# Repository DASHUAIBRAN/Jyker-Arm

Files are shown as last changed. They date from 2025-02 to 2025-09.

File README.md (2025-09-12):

# jyker机械臂

#### 硬件介绍
jyker 机械臂是一款开源的3D 打印机械臂，硬件分为4个部分
1.  3D打印的骨架 ，可以打开models 文件夹查看，也可以在makerworld上可以直接打印，传送门：https://makerworld.com.cn/zh/models/958314#profileId-973439
2.  3D打印的减速机4个以及金属减速机1个，也可以直接在makerworld上直接找到：https://makerworld.com.cn/zh/models/807709#profileId-785035
3.  FOC 板子可以上淘宝购买：https://item.taobao.com/item.htm?abbucket=17&id=975169994702 
或者去立创开源广场获取制板文件：https://oshwhub.com/dashuaibran/works ， 
FOC电机源码在firmware/CtrlStepDriver 目录下，
电机上位机源码在 MotorControl 目录下

#### 螺钉安装（打印减速器版本）
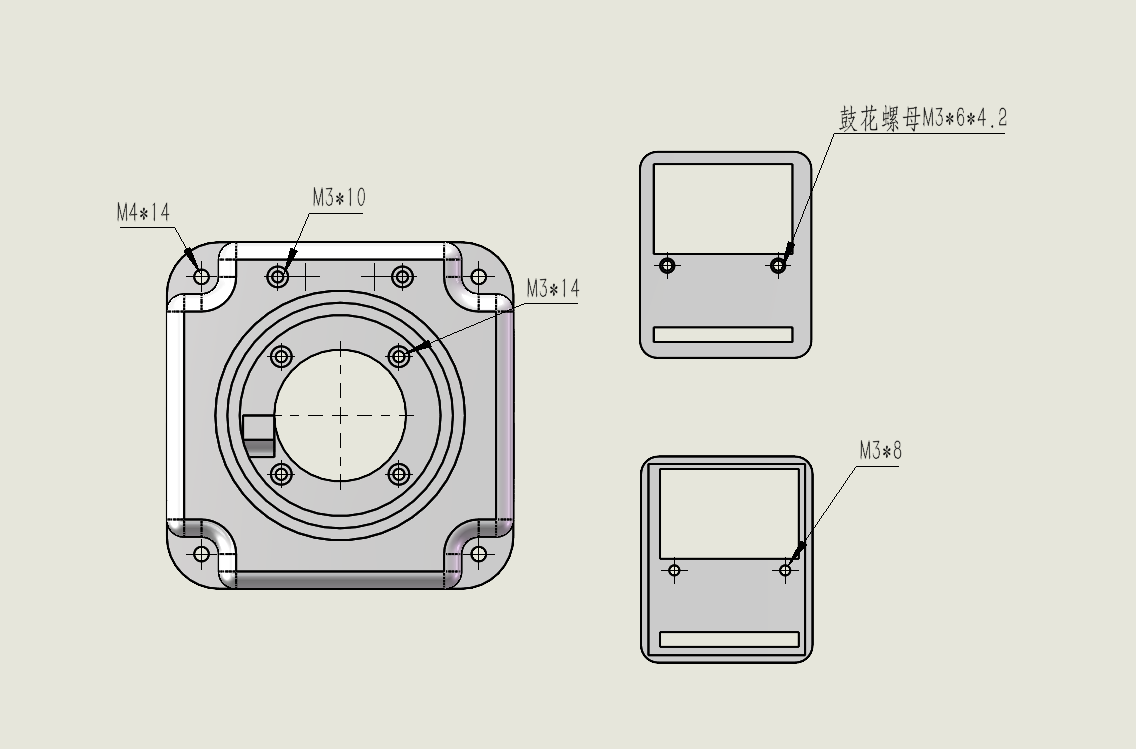
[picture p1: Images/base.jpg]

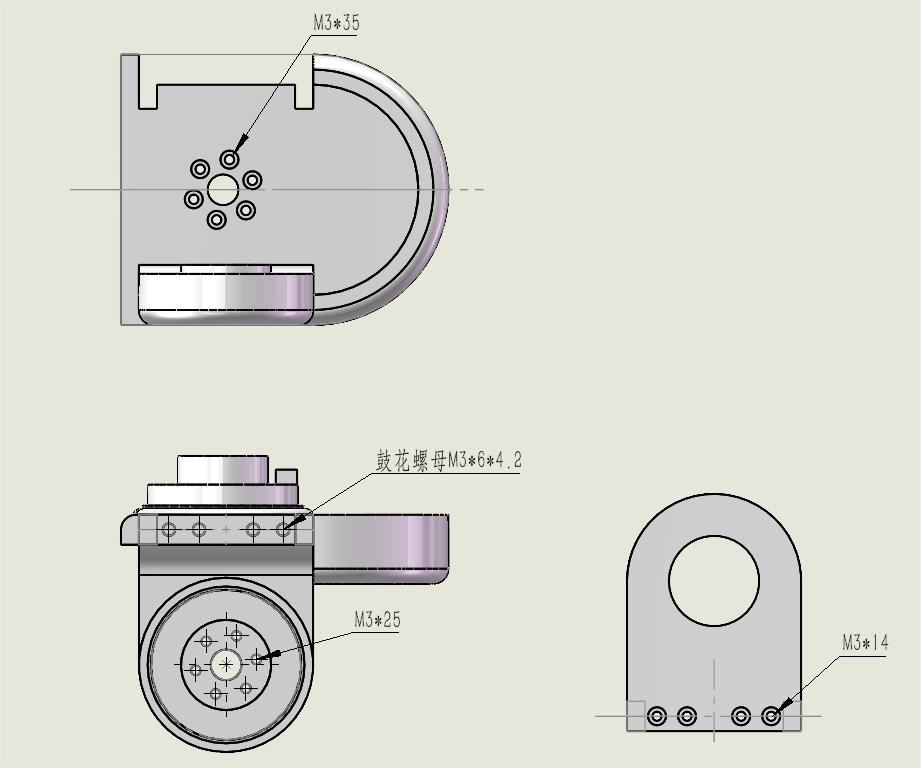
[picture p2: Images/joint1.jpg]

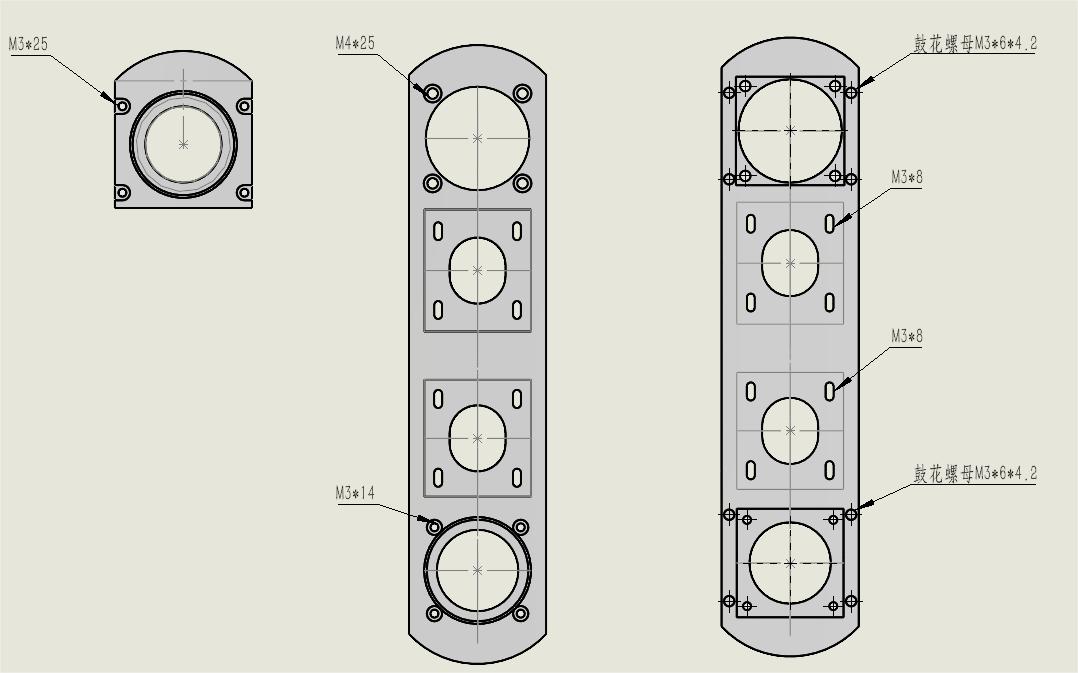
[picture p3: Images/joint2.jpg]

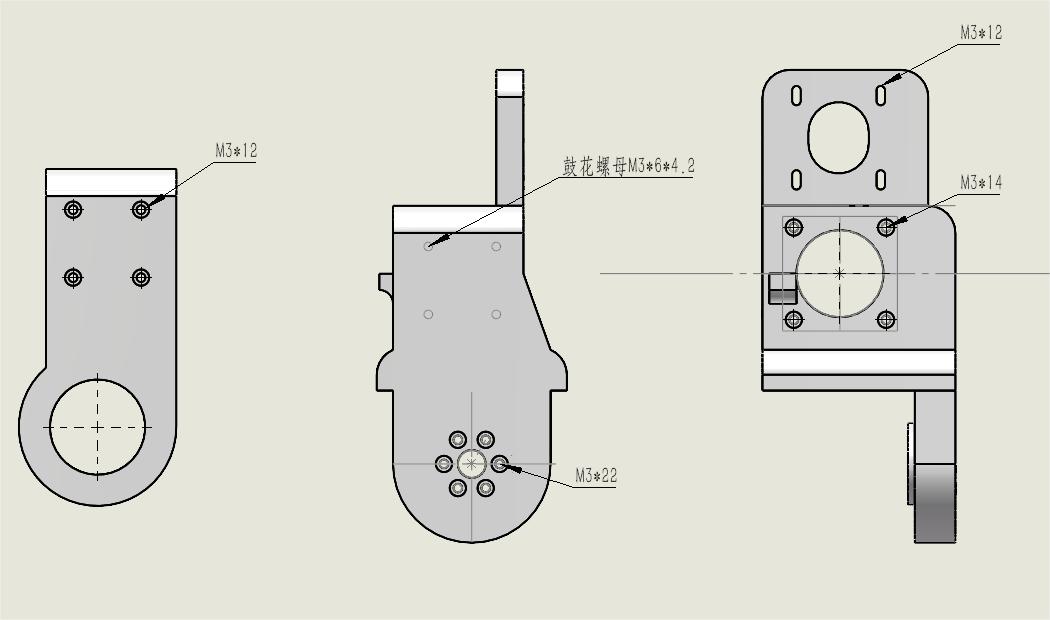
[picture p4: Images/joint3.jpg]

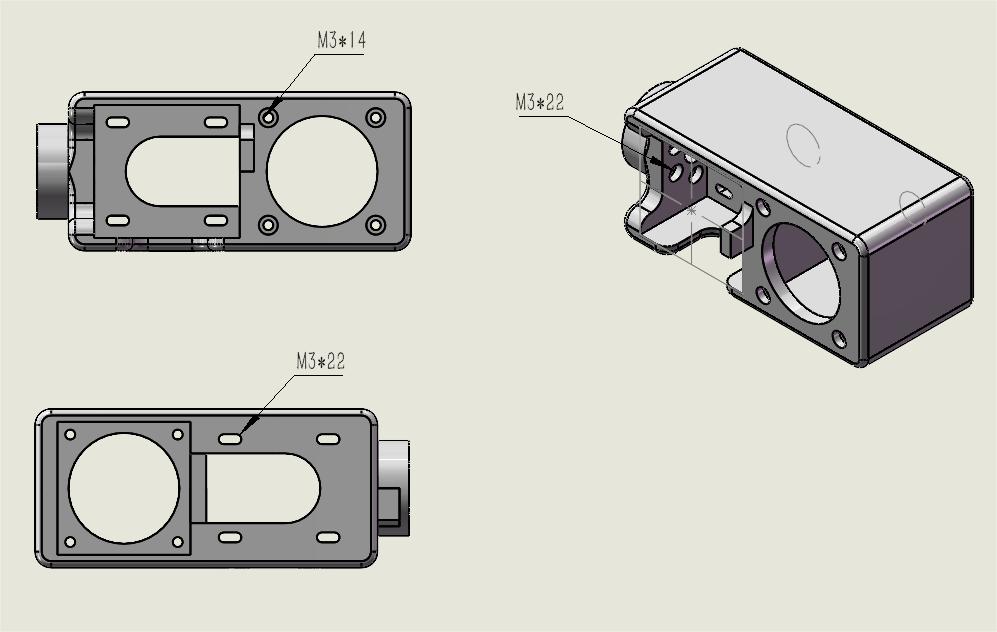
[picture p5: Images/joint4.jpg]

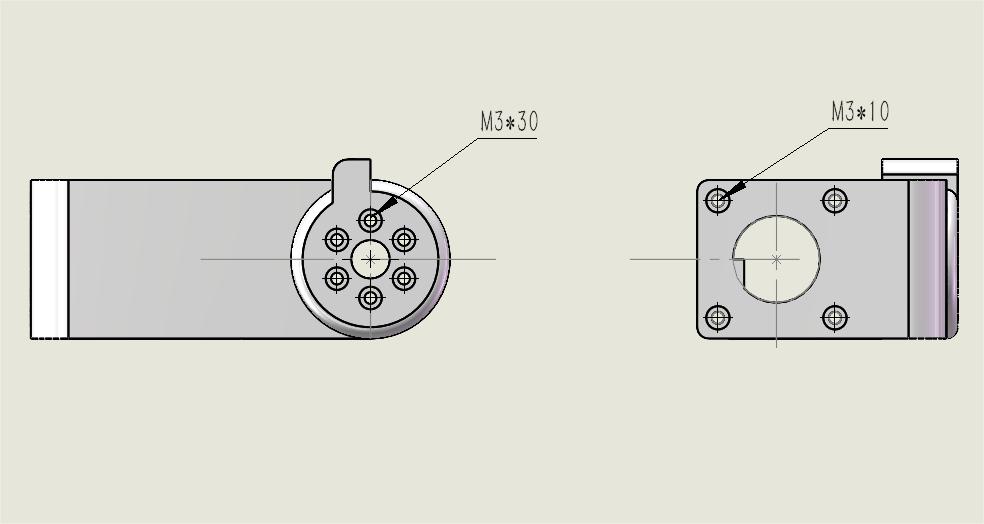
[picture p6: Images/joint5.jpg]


#### 螺钉安装（金属减速器版本）
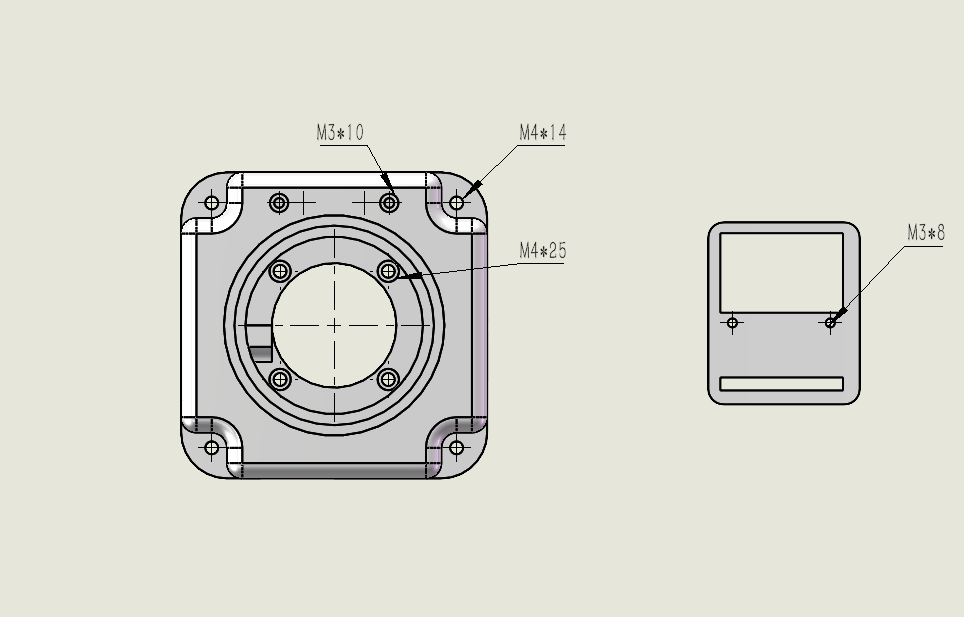
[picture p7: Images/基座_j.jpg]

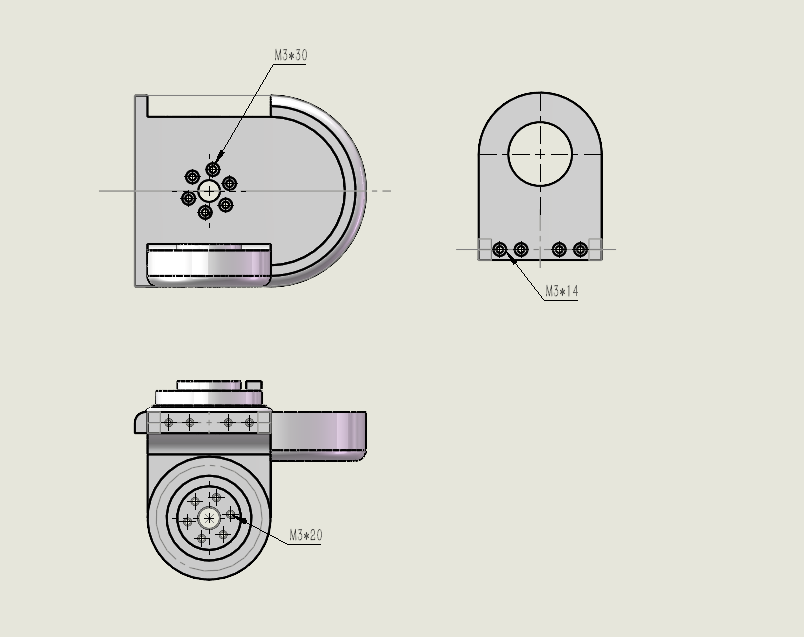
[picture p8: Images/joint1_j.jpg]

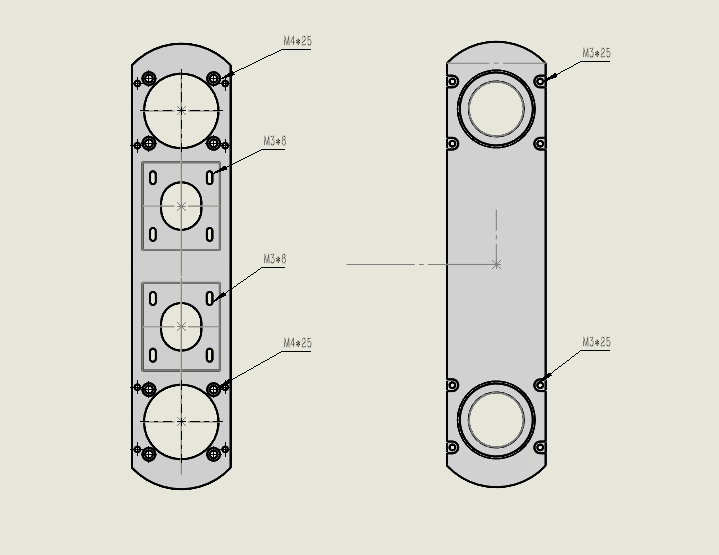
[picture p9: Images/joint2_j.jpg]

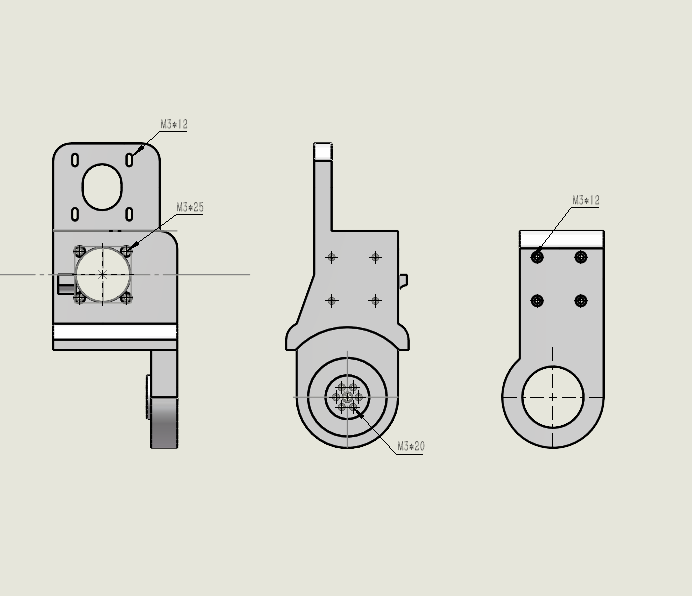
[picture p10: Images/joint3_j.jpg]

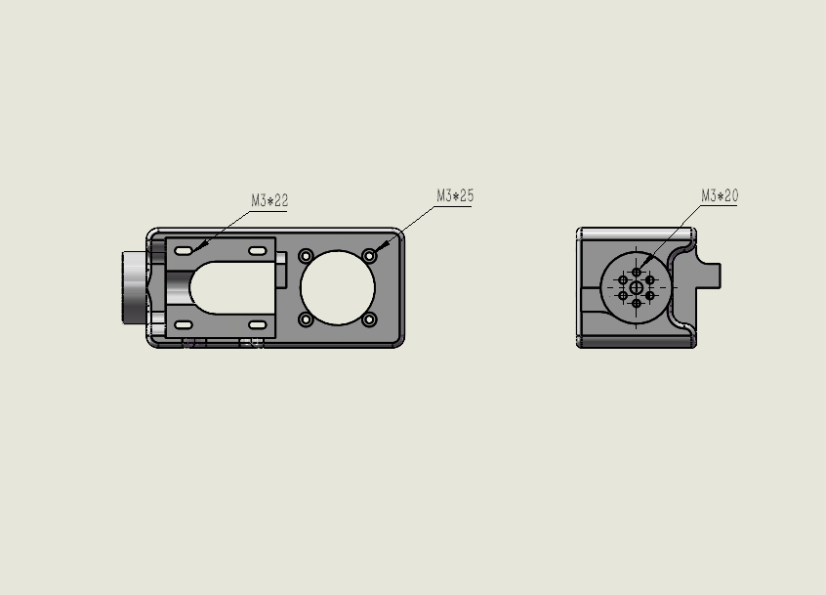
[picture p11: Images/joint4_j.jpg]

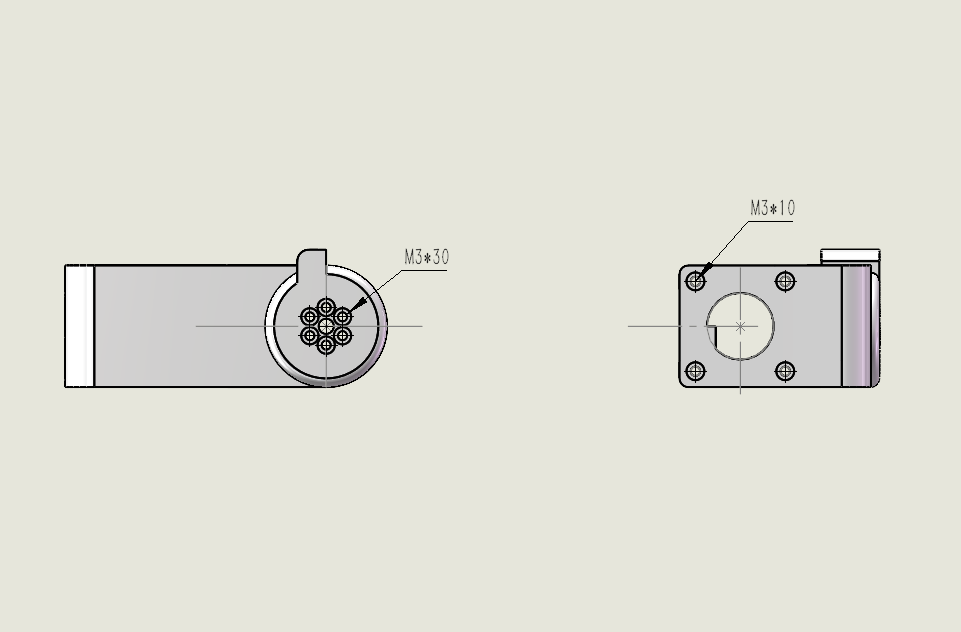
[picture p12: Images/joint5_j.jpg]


#### 电机对应位置以及ID设置
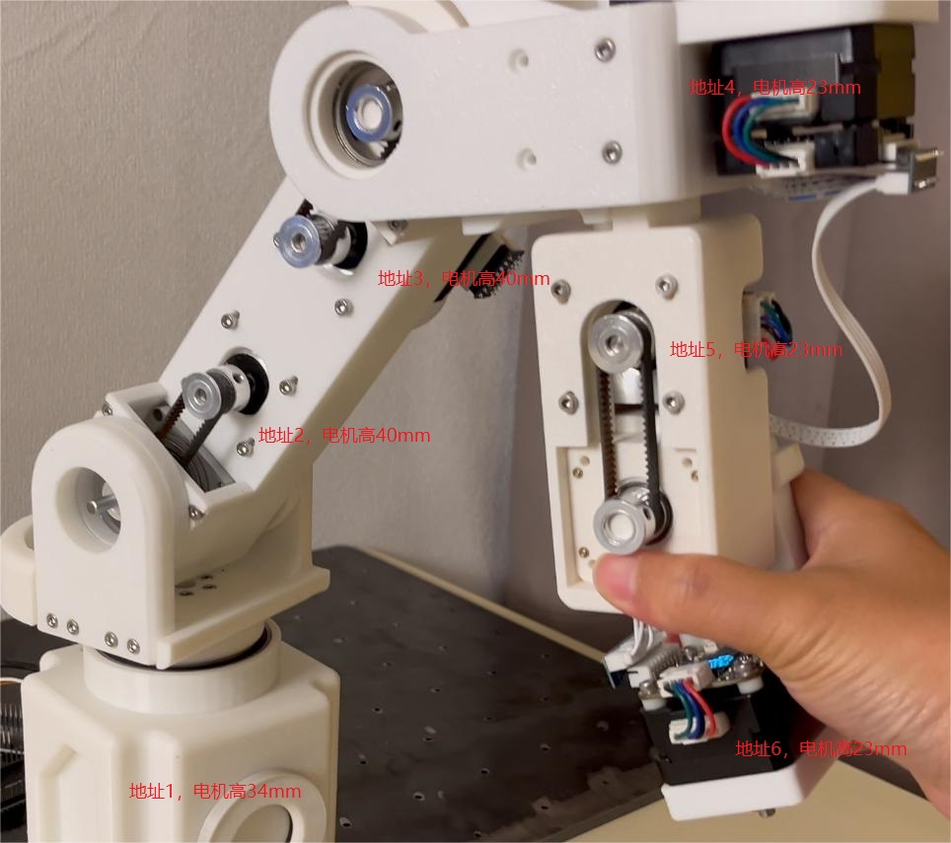
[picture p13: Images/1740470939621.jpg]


#### 夹爪
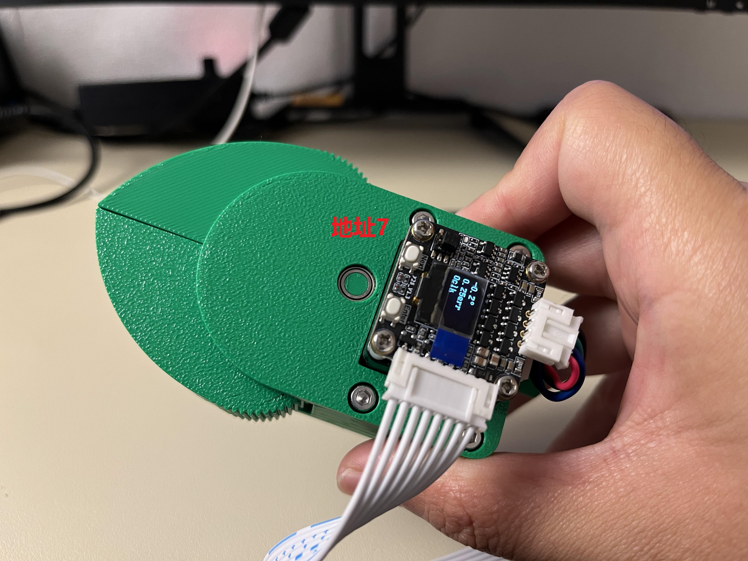
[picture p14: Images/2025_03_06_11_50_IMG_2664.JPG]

1.  模型在models/Claw 下面，也可以在makerworld上可以直接打印，传送门：https://makerworld.com.cn/zh/models/1006461-jyker-jia-zhua#profileId-1033256
2.  软件还是 HMIcode/BigProject目录下。

#### 安装教程
https://www.bilibili.com/video/BV1816yYHE2C/?vd_source=d81fb23162409ba3460eb9de840d7b4a

#### 软件使用

1. TODO

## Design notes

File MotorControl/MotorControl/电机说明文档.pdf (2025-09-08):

目录

## 一、电机说明

1.1.电机接口图

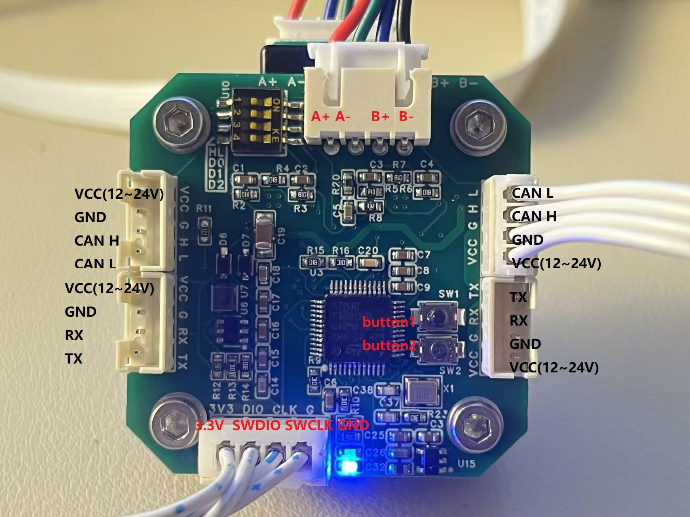
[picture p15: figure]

1.2.电机接口说明

1.2.1 电机支持串口通讯以及 can 通讯。
1.2.2 电机有两个串口通讯口，以及两个 can 通讯口，均可连接接线板，有两个通讯口是方 便后续串联电机。
1.2.3 串口通讯引脚有 VCC、GND、RX、TX，VCC 是电源输入，接受 12V 到 24V 之间的宽电 压，GND 接地，RX 接通讯的 TX 端 ，TX 接通讯的 RX 端。
1.2.4 CAN 通讯引脚有 VCC、GND、CAN H 、CAN L，VCC 是电源输入，接受 12V 到 24V 之 间的宽电压，GND 接地，CANH 接通讯的 CANH ,CANL 接通讯的 CANL。
1.2.5 支持 SWD 进行调试或编程，该接口可接 ST-LINK、J-LINK、DAP-LINK，四个引脚分别是 3V3、DIO、CLK、GND。
1.2.6 电机接口 A+ A- B+ B- 可接 42 步进电机。
1.2.7 有两个 button ,button1 长按可校准电机、button2 单击可使能电机或是失能电机。

### 1.3 电机接线示意图

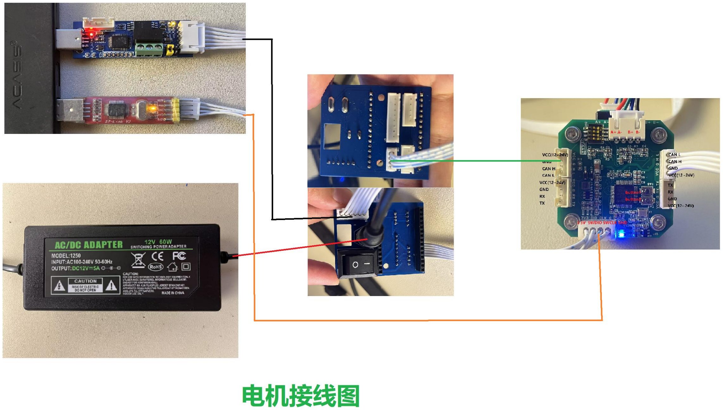
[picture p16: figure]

### 1.4 电机接线说明

1.4.1 红线是电源与中间集线板的连线，并没有什么讲究，直接插入就行。
1.4.2 橙色线是 ST-Link 与电机控制板之间的连线，请对准接口。
1.4.3 黑色线是 USB 转 CAN 模块与集线板的连接，如果购买 UP 的 USB 转 CAN 模块接口使 用 XH2.54 反向线连接便可以，如果购买其他品牌需要对应上接线定义。
1.4.4 绿色线是转接板与电机控制板的连线，可以使用 PH2.0 反向的线连接，如果使用面包 板或者其他接线方式，需要核对好接线定义。
1.4.5 以上所有可以在这个链接买到：
https://mall.bilibili.com/neul-next/detailuniversal/detail.html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 hare (https://mall.bilibili.com/neul-next/detailuniversal/detail.html?isMerchant=1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)

## 1.5 ID 设置

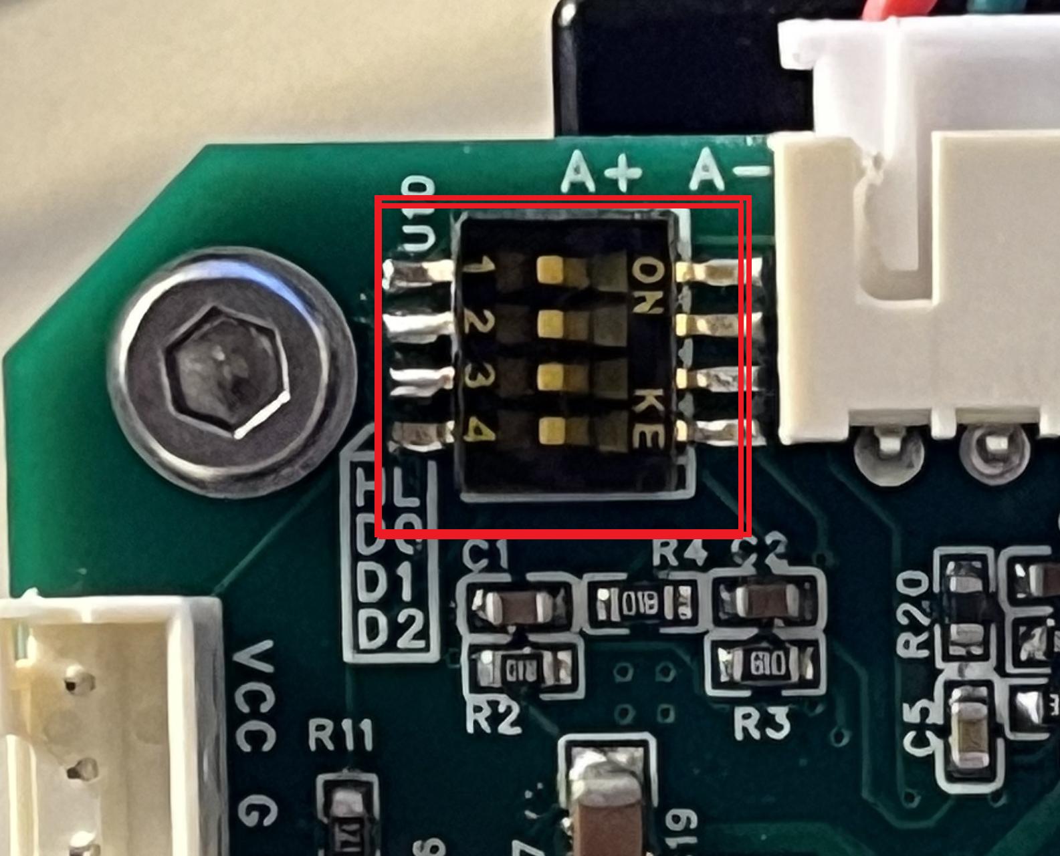
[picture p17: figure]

1.5.1 电机的 ID 有电机右上角的拨码器设置，由图可知有 1、2、3、4 四个拨码开关。

1.5.2 拨码开关 1 是通知 CANH 和 CANL 是通过 120R 电阻接通，在多点电机串联的情况下， 中间电机拨码开关关闭，最后一个电机拨码开关需要关闭。

1.5.3 拨码开关 2、3、4 用于控制电机 ID，分别代表 4、2、1，举例说明，像上图拨码开关
2、3、4 都关闭，电机 ID 为 4*0+2*0+1*0 =0 ；
如果 4、3 关闭，2 打开，电机 ID 为：4×0 + 2×0 + 1×1 = 1
如果 4、2 关闭，3 打开，电机 ID 为：4×0 + 2×1 + 1×0 = 2
如果 4 关闭，3、2 打开，电机 ID 为：4×0 + 2×1 + 1×1 = 3 如果 3、2 关闭，4 打开，电机 ID 为：4×1 + 2×0 + 1×0 = 4
如果 3 关闭，4、2 打开，电机 ID 为：4×1 + 2×0 + 1×1 = 5
如果 2 关闭，4、3 打开，电机 ID 为：4×1 + 2×1 + 1×0 = 6
如果 4、3、2 拨码开关都打开，电机 ID 为：4×1 + 2×1 + 1×1 = 7

## 二、通讯协议说明

### 2.1 使用 ID 读取信息

## 2.1.1 节点地址与帧 ID

节点 ID (Node ID): 驱动器通过拨码开关或配置命令设置其唯一的节点 ID，范围为 0x00 到
0x07。
命令帧 ID (Command ID): 上位机发送命令的 ID 格式为 0x0XX，其中 XX 为命令码。
响应帧 ID (Response ID): 驱动器发送响应的 ID 格式为 (NodeID << 7) | 0x2X。
例如，节点 ID 为 3 的驱动器，其响应 ID 的计算为 (3 << 7) | 0x21 = 0x180 | 0x21 = 0x1A1。
数据格式： 所有浮点数和 32 位整数均按小端字节序（Little-Endian）传输。

## 2.1.2 命令集

2.1.2.1 控制命令 (0x00 ~ 0x0F)

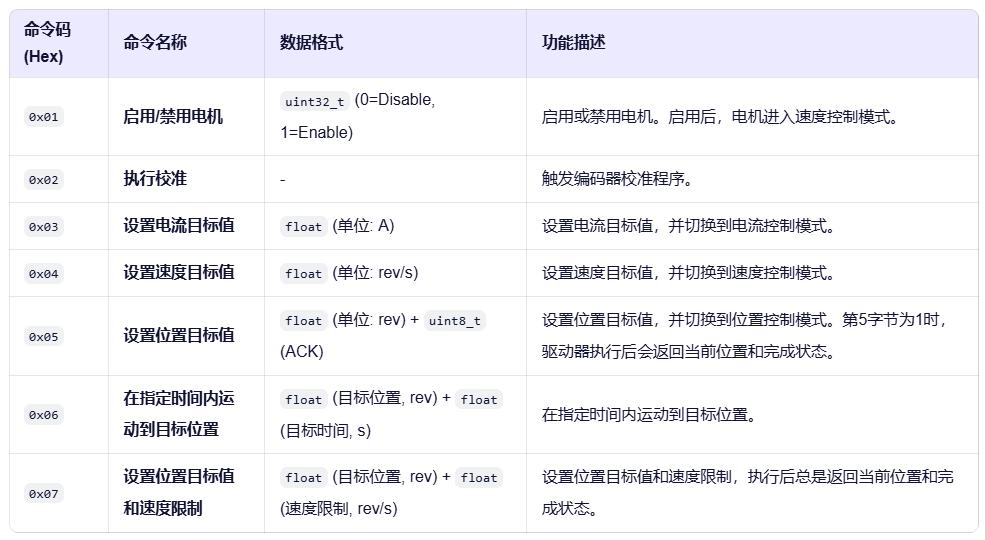
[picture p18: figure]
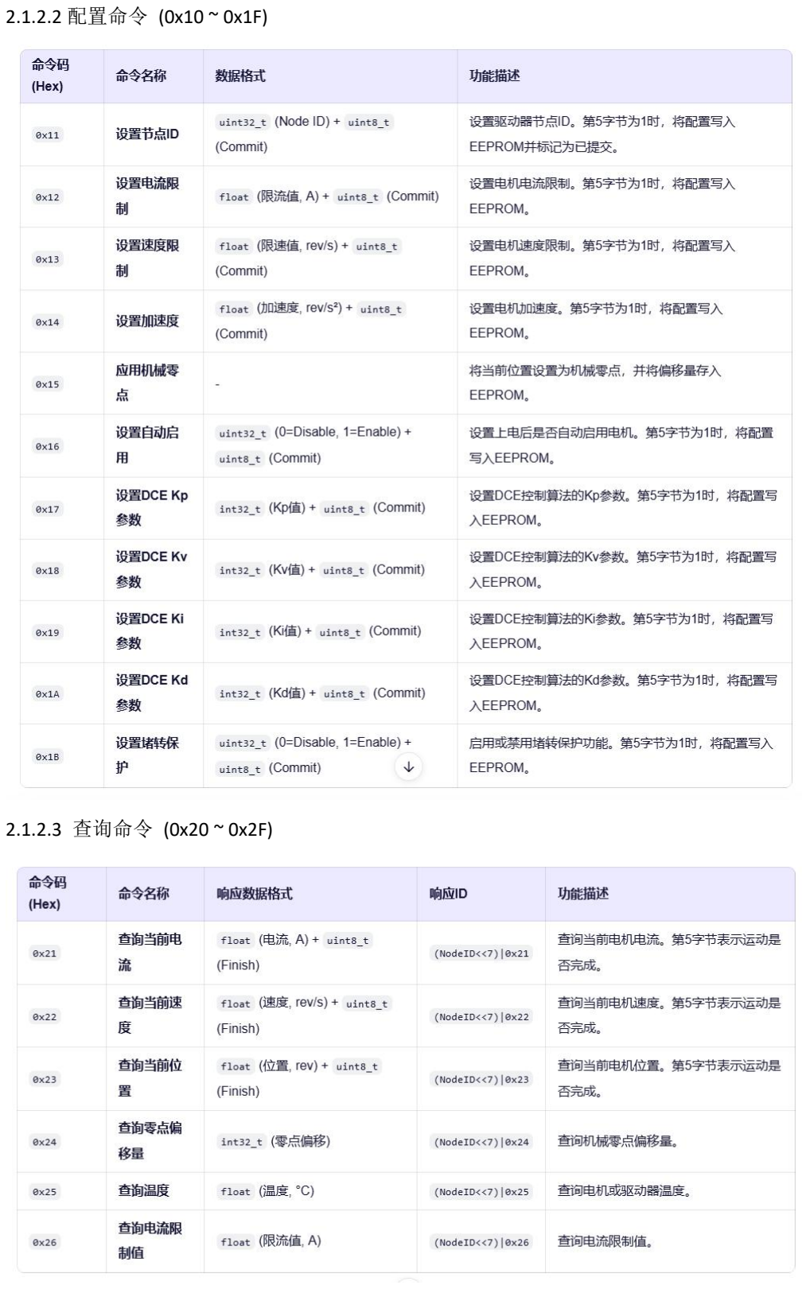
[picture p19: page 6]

2.1.2.2 配置命令 (0x10 ~ 0x1F)

2.1.2.3 查询命令 (0x20 ~ 0x2F)

## 三、上位机说明

### 3.1 上位机长这个样

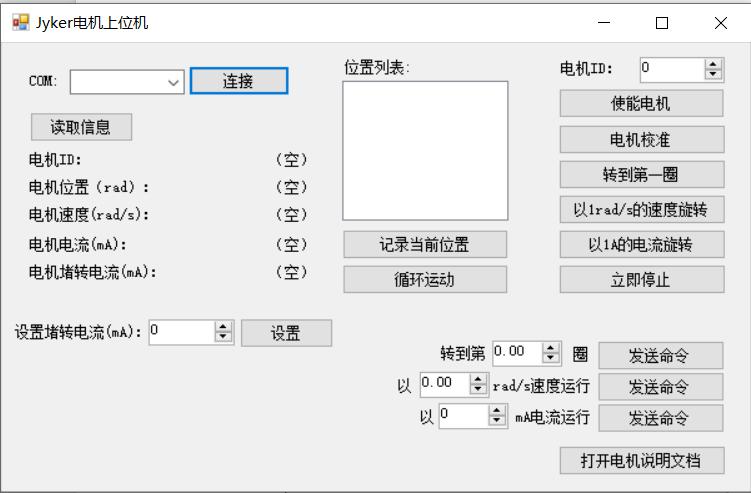
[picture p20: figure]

### 3.2 上位机使用说明

## 3.2.1 连接设备

使用 USB 线将电机驱动器连接到电脑。
打开上位机软件。
选择串口：点击“COM端口”下拉框，软件会自动列出所有可用的USB串口（如 COM3, COM4）。 建立连接：从列表中选择正确的串口号，然后点击 “连接” 按钮。 连接成功后，按钮文字会变为 “断开连接”，且串口号选择框将被锁定。 若连接失败，请检查 USB 线连接、驱动是否安装正确，并尝试重新选择串口。

### 3.2.2 读取电机状态

在 “电机 ID” 的数值框中输入目标电机的 ID 号。

点击 “读取信息” 按钮。
软件将自动查询并显示该电机的以下信息：
电流 (A)
速度 (rev/s)
位置 (rev)
限流值 (A)

### 3.2.3 基本电机控制

使能/失能电机：
点击 “使能电机” 按钮，电机将通电并准备运行（按钮变为“失能电机”）。 点击 “失能电机” 按钮，电机将断电（按钮变回“使能电机”）。 执行校准：
点击 “校准电机” 按钮，驱动器将执行编码器校准程序。
快速测试（以 1 单位运行）：
转一圈：点击此按钮，电机将旋转一整圈。
一圈每秒：点击此按钮，电机将以每秒一圈的速度旋转。
1A 电流：点击此按钮，电机将以 1A 的电流运行。 立即停止：
点击 “马上停止” 按钮，电机将立即停止运动。

### 3.2.4 参数设置与目标控制

设置目标值：
在对应的数值框中输入目标值。
点击右侧的 “设置” 按钮。
设置位置：输入目标圈数，点击“设置”让电机运动到该位置。 设置速度：输入目标速度（圈/秒），点击“设置”让电机以该速度运行。 设置电流：输入目标电流（A），点击“设置”让电机以该电流运行。 设置限流：输入电流限制值（A），点击“设置”来保护电机。

### 3.2.5 位置循环运动

记录位置点：
手动移动电机到一个目标位置。
点击 “记录当前位置” 按钮，该位置（圈数）将被添加到下方的列表中。 重复此过程，记录所有需要循环运动的位置点。
启动循环运动：
点击 “循环运动” 按钮。
软件将按列表中的顺序，依次发送指令让电机运动到每一个记录的位置点。 电机到达一个点后，会自动开始向下一个点运动。
停止循环：

点击 “马上停止” 按钮可以立即中断循环运动。

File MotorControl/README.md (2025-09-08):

电机控制上位机系统
基于 CAN 通信协议的智能电机控制上位机软件

本项目是一个用于控制支持 CAN 通信的智能电机驱动器的上位机软件，支持电机状态读取、基本控制、参数设置和循环运动功能。

📋 功能特性
✅ 通过串口（SLCAN协议）与电机通信
✅ 支持多电机 ID 识别与控制
✅ 实时读取电流、速度、位置、限流值
✅ 电机使能/失能、校准、快速测试
✅ 目标位置、速度、电流设置
✅ 位置循环运动（支持记录与自动循环）
✅ 图形化界面，操作简单直观
🛠️ 硬件连接
使用 USB 线将电机驱动器连接至电脑。
驱动器支持 CAN 或串口通信，确保接线正确。
每台电机通过 拨码开关 设置唯一 ID（0-7）：
拨码开关 2、3、4 分别代表权重 1、2、4
例如：开关2打开，3、4关闭 → ID = 1
💻 软件使用说明
1. 连接设备
打开上位机软件。
从 “COM端口” 下拉框中选择正确的串口号（如 COM3）。
点击 “连接” 按钮建立连接。
✅ 连接成功后，按钮变为“断开连接”，串口选择框将被锁定。

2. 读取电机状态
在 “电机ID” 输入框中输入目标电机 ID。
点击 “读取信息” 按钮。
软件将显示：
电流 (A)
速度 (rev/s)
位置 (rev)
限流值 (A)
3. 基本控制
操作	说明
使能电机	通电，准备运行（点击后变为“失能电机”）
校准电机	执行编码器校准程序
转一圈	控制电机旋转一整圈
一圈每秒	控制电机以 1 rev/s 的速度运行
1A电流	控制电机以 1A 电流运行
马上停止	立即停止电机运动
4. 参数设置
在对应输入框中输入目标值，点击右侧 “设置” 按钮：

设置位置：运动到指定圈数
设置速度：以指定速度运行（rev/s）
设置电流：以指定电流运行（A）
设置限流：设置电流保护上限（A）
5. 位置循环运动
记录位置点：
手动移动电机到目标位置。
点击 “记录当前位置”，位置将添加到列表。
重复操作，记录多个点。
启动循环：
点击 “循环运动”，电机将按顺序循环运动到每个记录点。
停止循环：
点击 “马上停止” 可随时中断。
📄 通信协议（CAN）
命令码	功能	数据格式
0x01	使能/禁能	uint32_t
0x02	校准	-
0x03	设置电流	float (A)
0x04	设置速度	float (rev/s)
0x05	设置位置	float (rev) + ACK
0x21~0x26	查询状态	返回 float + 状态
详细协议请参考 CAN通信协议文档

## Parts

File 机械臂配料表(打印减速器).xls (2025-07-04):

材料 | 数量 | 备注 | 价格 | tb链接
42步进电机 40mm 长 | 2 |  | 454.65 | https://shop113302005.taobao.com/
42步进电机 23mm 长 | 3
42步进电机 34mm 长 | 1
42电机 foc 控制板 | 6
12V 电源适配器 | 1 | 12V5A | 35 | https://detail.tmall.com/item.htm?from=cart&id=645461549857&skuId=5151504175110
同步轮 2GT（20齿高16)内孔8mm | 3 |  | 10.79 | https://item.taobao.com/item.htm?_u=gvv76ou9fdf&id=528687341718&skuId=4086878159095
同步轮 2GT（20齿高16)内孔5mm | 5 |  | 10.79 | https://item.taobao.com/item.htm?_u=gvv76ou9fdf&id=528687341718&skuId=4086878159093
同步带 2GT-140MM（防滑齿面） | 4 |  | 14.18 | https://item.taobao.com/item.htm?_u=gvv76ou7974&id=677341747083&skuId=4863997853174
3d 打印谐波减速器第四版不出轴 | 1 | 在我另外一个开源链接里 | 53.06
3d 打印谐波减速器第四版出轴 | 3 | 在我另外一个开源链接里
金属谐波减速机 | 1 | MINIF 11-50（法兰输出） 可配42步进 | 260 | https://item.taobao.com/item.htm?_u=pvv76ou91cf&id=702811518003
定位销 | 1 | 5mm* 50mm | 5 | https://item.taobao.com/item.htm?_u=4vv76ou892c&id=754846150226&skuId=5376758051412
轴承 内径50mm外径65厚度7mm | 1 |  | 14.5 | https://item.taobao.com/item.htm?_u=gvv76oudd5c&id=732883595520&skuId=5298946319109
轴承 内径40mm外径52mm厚度7mm | 3 |  |  | https://item.taobao.com/item.htm?_u=gvv76oudd5c&id=732883595520&skuId=5146788376594
XH2.54mm 蓝白红白排线 8p 400mm | 2 | 建议去up工房买，单买算起来有点亏：https://mall.bilibili.com/neul-next/detailuniversal/detail.html?isMerchant=1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 | 10 | https://item.taobao.com/item.htm?_u=pvv76ou2ebb&id=520551443113&sku_properties=-2%3A-7
PH2.0mm蓝白红白排线 4p 400mm | 1
PH2.0mm蓝白红白排线 4p 200mm | 3
PH2.0mm蓝白红白排线 4p 100mm | 1
XH2.54mm 插座 4p | 1 |  | 16 | https://detail.tmall.com/item.htm?_u=pvv76oud8b8&id=609069698010&skuId=4450119279579
XH2.54mm 插座 5p | 1
XH2.54mm 插座 6p | 1
XH2.54mm 插座 8p | 1
PH2.00mm 插座 4p | 10
PH2.00mm 插座 8p | 1
2.54mm单排母座 8p | 5 |  | 10 | https://item.taobao.com/item.htm?_u=pvv76ou243a&id=543256078293&skuId=3268555613590
2.54mm单排母座 15p | 2
接线板子大 | 1 |  | 60 | https://oshwhub.com/dashuaibran/mechanical-arm-line-connector
接线板子小1 | 4
接线板子小2 | 1
3d 打印件 |  |  | 200
内六角螺丝圆柱螺钉M4*14 | 8 | 底座和底板之间的固定 | 60 | https://detail.tmall.com/item.htm?from=cart&id=664122354131&skuId=4959959431045
内六角螺丝圆柱螺钉M3*40 | 10 | 基座与第一轴的连接、基座电机和减速器连接
内六角螺丝圆柱螺钉M3*16 | 4 | 固定减速器和基座
注塑铜螺母滚花螺母 M3*6*4.2 | 8
内六角螺丝圆柱螺钉M3*12 | 50 | 2,3,4,5关节减速器固定
内六角螺丝圆柱螺钉M3*8 | 50 | 2,3,4关机电机固定
内六角螺丝圆柱螺钉M3*10
内六角螺丝圆柱螺钉M3*12
内六角螺丝圆柱螺钉M3*14
内六角螺丝圆柱螺钉M3*22 | 4 | 5关节电机固定
内六角螺丝圆柱螺钉M3*30 | 6 | 第3轴和减速器连接
内六角螺丝圆柱螺钉M3*20 | 4 | 第4轴和减速器连接
内六角螺丝圆柱螺钉M3*35
内六角螺丝圆柱螺钉M3*25 | 6 | 第5轴和减速器连接
 |  |  | 1213.97

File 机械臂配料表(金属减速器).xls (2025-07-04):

材料 | 数量 | 备注 | 价格 | tb链接
42步进电机 40mm 长 | 2 |  | 454.65 | https://shop113302005.taobao.com/
42步进电机 23mm 长 | 3
42步进电机 34mm 长 | 1
42电机 foc 控制板 | 6
12V 电源适配器 | 1 | 12V5A | 35 | https://detail.tmall.com/item.htm?from=cart&id=645461549857&skuId=5151504175110
同步轮 2GT（20齿高16)内孔8mm | 3 |  | 10.79 | https://item.taobao.com/item.htm?_u=gvv76ou9fdf&id=528687341718&skuId=4086878159095
同步轮 2GT（20齿高16)内孔5mm | 5 |  | 10.79 | https://item.taobao.com/item.htm?_u=gvv76ou9fdf&id=528687341718&skuId=4086878159093
同步带 2GT-140MM（防滑齿面） | 4 |  | 14.18 | https://item.taobao.com/item.htm?_u=gvv76ou7974&id=677341747083&skuId=4863997853174
金属谐波减速机 42_50 | 1 | MINIF 11-50（法兰输出） 可配42步进 | 260 | https://item.taobao.com/item.htm?_u=pvv76ou91cf&id=702811518003
金属谐波减速机 42_30 | 2 | MINIF11-30（法兰输出） 可配42步进 | 520 | https://item.taobao.com/item.htm?_u=pvv76ou91cf&id=702811518003
金属谐波减速机 30_30 |  | MINIF-8-30（法兰输出） 可配35步进 | 600 | https://item.taobao.com/item.htm?_u=pvv76ou91cf&id=702811518003&skuId=4952528325501
定位销 | 4 | 5mm* 50mm | 5 | https://item.taobao.com/item.htm?_u=4vv76ou892c&id=754846150226&skuId=5376758051412
轴承 内径50mm外径65厚度7mm | 1 |  | 14.5 | https://item.taobao.com/item.htm?_u=gvv76oudd5c&id=732883595520&skuId=5298946319109
轴承 内径40mm外径52mm厚度7mm | 2 |  |  | https://item.taobao.com/item.htm?_u=gvv76oudd5c&id=732883595520&skuId=5146788376594
轴承 内径5mm外径10mm厚度4mm | 4 | 用于固定减速器的底部 | 10 | https://detail.tmall.com/item.htm?abbucket=17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
XH2.54mm 蓝白红白排线 8p 400mm | 2 | 建议去up工房买，单买算起来有点亏：https://mall.bilibili.com/neul-next/detailuniversal/detail.html?isMerchant=1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 | 10 | https://item.taobao.com/item.htm?_u=pvv76ou2ebb&id=520551443113&sku_properties=-2%3A-7
PH2.0mm蓝白红白排线 4p 400mm | 1
PH2.0mm蓝白红白排线 4p 200mm | 3
PH2.0mm蓝白红白排线 4p 100mm | 1
XH2.54mm 插座 4p | 1 |  | 16 | https://detail.tmall.com/item.htm?_u=pvv76oud8b8&id=609069698010&skuId=4450119279579
XH2.54mm 插座 5p | 1
XH2.54mm 插座 6p | 1
XH2.54mm 插座 8p | 1
PH2.00mm 插座 4p | 10
PH2.00mm 插座 8p | 1
2.54mm单排母座 8p | 5 |  | 10 | https://item.taobao.com/item.htm?_u=pvv76ou243a&id=543256078293&skuId=3268555613590
2.54mm单排母座 15p | 2
接线板子大 | 1 |  | 60 | https://oshwhub.com/dashuaibran/mechanical-arm-line-connector
接线板子小1 | 4
接线板子小2 | 1
3d 打印件 |  |  | 200
内六角螺丝圆柱螺钉M4*14 | 8 |  | 60 | https://detail.tmall.com/item.htm?from=cart&id=664122354131&skuId=4959959431045
内六角螺丝圆柱螺钉M4*30 | 12
内六角螺丝圆柱螺钉M3*12 | 8
内六角螺丝圆柱螺钉M3*8 | 10
内六角螺丝圆柱螺钉M3*10 | 2
内六角螺丝圆柱螺钉M3*14 | 4
内六角螺丝圆柱螺钉M3*22 | 4
内六角螺丝圆柱螺钉M3*30 | 6
内六角螺丝圆柱螺钉M3*20 | 18
内六角螺丝圆柱螺钉M3*25 | 16
 |  |  | 2290.91

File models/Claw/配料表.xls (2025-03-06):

材料 | 数量 | 备注 | 链接
3D 打印件 | 1 |  | https://makerworld.com.cn/zh/models/1006461-jyker-jia-zhua#profileId-1033256
28电机以及FOC控制板 | 1 | 电机使用28-28长磁柱电机就行 | https://item.taobao.com/item.htm?_u=6vv76ou3929&id=692429189361&skuId=5731955776564
轴承15*10*4 | 1 |  | https://item.taobao.com/item.htm?_u=6vv76ou8b88&id=642277669910&sku_properties=122276018%3A20213
轴承10*5*4 | 6 |  | https://item.taobao.com/item.htm?_u=6vv76ou7de7&id=674305780577&sku_properties=122276018%3A20213
螺钉 M3*35 | 4 |  | https://detail.tmall.com/item.htm?_u=6vv76ou5bd4&id=664122354131
滚花螺母 M3*6*4.2 | 4 |  | https://detail.tmall.com/item.htm?_u=6vv76ou55ed&id=580863677562

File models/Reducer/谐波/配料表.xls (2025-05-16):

物料 | 数量
轴承 6706-ZZ【30*37*4】 | 1
轴承 内径12外径18厚度4 | 1
轴承 内径10外径15厚度4 | 1
注塑铜螺母滚花螺母 M3*6*4.2 | 10
注塑铜螺母滚花螺母 M2*6*3.2 | 4
钢圆头内六角螺丝圆柱螺钉 M2*35 (https://item.taobao.com/item.htm?spm=a1z09.2.0.0.6c082e8d8Twp98&id=664122354131&_u=ovv76ou61e7) | 4
3D 打印件 |  | https://makerworld.com.cn/zh/models/807709-jyker-xie-bo-jian-su-qi#profileId-785035
304不锈钢球轴承滚珠不锈钢钢珠实心钢珠精密小钢珠钢球2.0毫米 (https://item.taobao.com/item.htm?spm=a1z09.2.0.0.6c082e8dgtaKx1&id=617921831316&_u=qvv76oud0d6) | 45~55颗
润滑油 | 1
500目砂纸 | 1

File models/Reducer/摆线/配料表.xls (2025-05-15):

物料 | 数量
轴承 6706-ZZ【30*37*4】 | 1
轴承 内径12外径18厚度4 | 3
轴承 内径15外径21厚度4 | 1
注塑铜螺母滚花螺母 M3*6*4.2 | 10
注塑铜螺母滚花螺母 M2*6*3.2 | 4
钢圆头内六角螺丝圆柱螺钉 M2*25 (https://item.taobao.com/item.htm?spm=a1z09.2.0.0.6c082e8d8Twp98&id=664122354131&_u=ovv76ou61e7) | 4
3D 打印件 |  | https://makerworld.com.cn/zh/models/1111439-jyker-bai-xian-jian-su-qi#profileId-1162764
M3*16 铁销 (https://item.taobao.com/item.htm?spm=a1z09.2.0.0.6c082e8dgtaKx1&id=617921831316&_u=qvv76oud0d6) | 27
润滑油 | 1

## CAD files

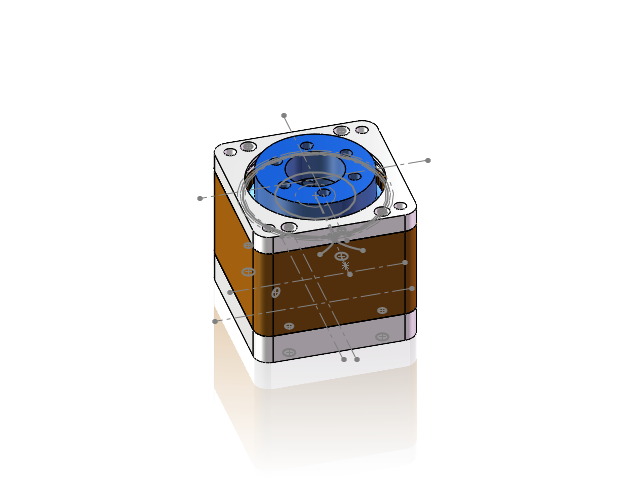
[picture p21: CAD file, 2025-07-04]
models/Arm/SW/3D打印减速器版本/谐波减速器/42电机总成第四版底无轴.SLDASM
42波发生器第四版底部中空
42底盖第四版
42钢轮第四版
42柔轮第四版
42柔轮内第四版
42顶盖第四版

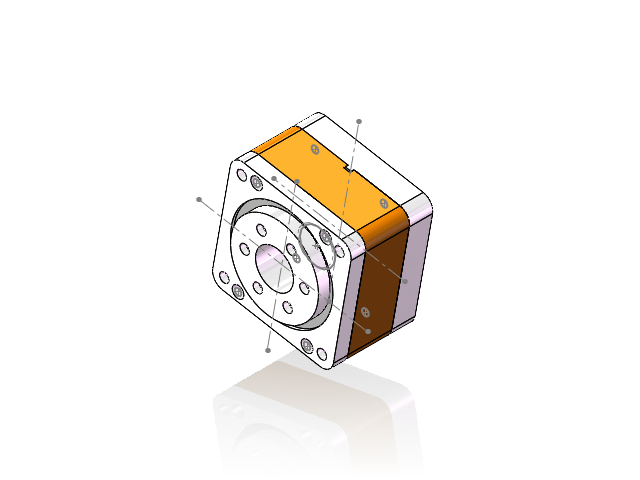
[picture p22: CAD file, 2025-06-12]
models/Reducer/摆线/SW/总成中空.SLDASM
摆轮 x 2
底盘
顶部
顶盖
偏心轮底部中空
偏心轮中部
中部

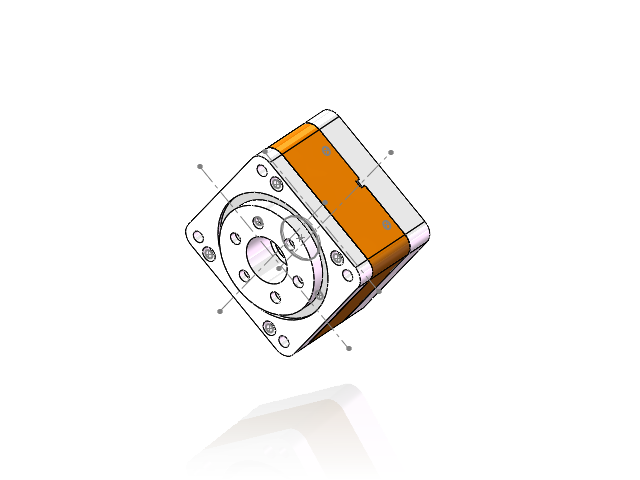
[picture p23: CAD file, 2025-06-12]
models/Reducer/摆线/SW/总成出轴.SLDASM
底盘
偏心轮底部
摆轮 x 2
顶部
顶盖
中部
偏心轮中部

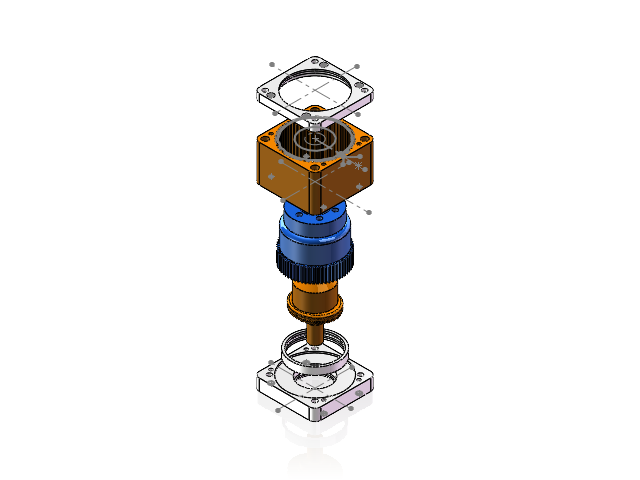
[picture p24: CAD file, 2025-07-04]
models/Arm/SW/3D打印减速器版本/谐波减速器/42电机总成第四版.SLDASM
42波发生器第四版
42底盖第四版
42顶盖第四版
42钢轮第四版
42柔轮第四版
42柔轮内第四版

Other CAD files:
models/Arm/SW/金属减速器版本/金属减速器/MINIF11步进电机42安装案例.sldasm-Part-10.SLDPRT
models/Arm/SW/金属减速器版本/金属减速器/MINIF8步进电机35安装案例.sldasm-Part-34.SLDPRT
models/Arm/SW/金属减速器版本/金属减速器/MINIF8步进电机35安装案例.sldasm-Part-4.SLDPRT
models/Arm/SW/金属减速器版本/金属减速器/MINIF8步进电机35安装案例.sldasm-Part-12.SLDPRT
models/Arm/SW/金属减速器版本/金属减速器/MINIF8步进电机35安装案例.sldasm-Part-38.SLDPRT
models/Arm/SW/金属减速器版本/金属减速器/MINIF8步进电机35安装案例.sldasm-Part-33.SLDPRT
models/Arm/SW/金属减速器版本/金属减速器/MINIF8步进电机35安装案例.sldasm-Part-16.SLDPRT
models/Arm/SW/金属减速器版本/金属减速器/MINIF8步进电机35安装案例.sldasm-Part-30.SLDPRT
models/Arm/SW/金属减速器版本/金属减速器/MINIF8步进电机35安装案例.sldasm-Part-26.SLDPRT
models/Arm/SW/金属减速器版本/金属减速器/MINIF8步进电机35安装案例.sldasm-Part-5.SLDPRT
models/Arm/SW/金属减速器版本/金属减速器/MINIF11步进电机42安装案例.sldasm-Part-16.SLDPRT
models/Arm/SW/金属减速器版本/金属减速器/MINIF11步进电机42安装案例.sldasm-Part-11.SLDPRT
models/Arm/SW/金属减速器版本/金属减速器/MINIF8步进电机35安装案例.sldasm-Part-45.SLDPRT
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

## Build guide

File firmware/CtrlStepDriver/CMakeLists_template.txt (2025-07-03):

#THIS FILE IS AUTO GENERATED FROM THE TEMPLATE! DO NOT CHANGE!
set(CMAKE_SYSTEM_NAME Generic)
set(CMAKE_SYSTEM_VERSION 1)
cmake_minimum_required(VERSION 3.20)

# specify cross compilers and tools
set(CMAKE_C_COMPILER arm-none-eabi-gcc)
set(CMAKE_CXX_COMPILER arm-none-eabi-g++)
set(CMAKE_ASM_COMPILER arm-none-eabi-gcc)
set(CMAKE_AR arm-none-eabi-ar)
set(CMAKE_OBJCOPY arm-none-eabi-objcopy)
set(CMAKE_OBJDUMP arm-none-eabi-objdump)
set(SIZE arm-none-eabi-size)
set(CMAKE_TRY_COMPILE_TARGET_TYPE STATIC_LIBRARY)

# project settings
project(Ctrl-Step-STM32-fw C CXX ASM)
set(CMAKE_CXX_STANDARD 17)
set(CMAKE_C_STANDARD 11)

#Uncomment for hardware floating point
#add_compile_definitions(ARM_MATH_CM4;ARM_MATH_MATRIX_CHECK;ARM_MATH_ROUNDING)
#add_compile_options(-mfloat-abi=hard -mfpu=fpv4-sp-d16)
#add_link_options(-mfloat-abi=hard -mfpu=fpv4-sp-d16)

#Uncomment for software floating point
#add_compile_options(-mfloat-abi=soft)

add_compile_options(-mcpu=cortex-m3 -mthumb -mthumb-interwork)
add_compile_options(-ffunction-sections -fdata-sections -fno-common -fmessage-length=0)

# uncomment to mitigate c++17 absolute addresses warnings
#set(CMAKE_CXX_FLAGS "${CMAKE_CXX_FLAGS} -Wno-register")

if ("${CMAKE_BUILD_TYPE}" STREQUAL "Release")
    message(STATUS "Maximum optimization for speed")
    add_compile_options(-Ofast)
elseif ("${CMAKE_BUILD_TYPE}" STREQUAL "RelWithDebInfo")
    message(STATUS "Maximum optimization for speed, debug info included")
    add_compile_options(-Ofast -g)
elseif ("${CMAKE_BUILD_TYPE}" STREQUAL "MinSizeRel")
    message(STATUS "Maximum optimization for size")
    add_compile_options(-Os)
else ()
    message(STATUS "Minimal optimization, debug info included")
    add_compile_options(-Og -g)
endif ()

include_directories(
        Core/Inc
        Drivers/STM32F1xx_HAL_Driver/Inc
        Drivers/STM32F1xx_HAL_Driver/Inc/Legacy
        Drivers/CMSIS/Device/ST/STM32F1xx/Include
        Drivers/CMSIS/Include
        Ctrl
        Ctrl/Sensor
        Ctrl/Signal
        Ctrl/LowLevel
        Ctrl/MotorControl
        UserApp
        Port
)

add_definitions(-DUSE_HAL_DRIVER -D__MICROLIB -DSTM32F1 -DSTM32F1xx -DSTM32F103xB)

file(GLOB_RECURSE SOURCES
        "startup/*.*"
        "Drivers/*.*"
        "Core/*.*"
        "Ctrl/*.*"
        "UserApp/*.*"
        "Port/*.*"
        )

set(LINKER_SCRIPT ${CMAKE_SOURCE_DIR}/STM32F103CBTx_FLASH.ld)

add_link_options(-Wl,-gc-sections,--print-memory-usage,-Map=${PROJECT_BINARY_DIR}/${PROJECT_NAME}.map)
add_link_options(-mcpu=cortex-m3 -mthumb -mthumb-interwork)
add_link_options(-T ${LINKER_SCRIPT})

add_executable(${PROJECT_NAME}.elf ${SOURCES} ${LINKER_SCRIPT})

set(HEX_FILE ${PROJECT_BINARY_DIR}/${PROJECT_NAME}.hex)
set(BIN_FILE ${PROJECT_BINARY_DIR}/${PROJECT_NAME}.bin)

add_custom_command(TARGET ${PROJECT_NAME}.elf POST_BUILD
        COMMAND ${CMAKE_OBJCOPY} -Oihex $<TARGET_FILE:${PROJECT_NAME}.elf> ${HEX_FILE}
        COMMAND ${CMAKE_OBJCOPY} -Obinary $<TARGET_FILE:${PROJECT_NAME}.elf> ${BIN_FILE}
        COMMENT "Building ${HEX_FILE}
Building ${BIN_FILE}")

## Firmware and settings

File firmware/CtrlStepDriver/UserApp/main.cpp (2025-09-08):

#include "common_inc.h"
#include "configurations.h"
#include "Platform/Utils/st_hardware.h"
#include "can.h"
#include <tim.h>


/* Component Definitions -----------------------------------------------------*/
BoardConfig_t boardConfig; //板卡配置
Motor motor;
TB67H450 tb67H450;
MT6816 mt6816;
EncoderCalibrator encoderCalibrator(&motor);
Button button1(1, 1000), button2(2, 3000);
void OnButton1Event(Button::Event _event);
void OnButton2Event(Button::Event _event);
Led statusLed;
/* Main Entry ----------------------------------------------------------------*/
void Main()
{
    uint64_t serialNum = GetSerialNumber();
    uint16_t defaultNodeID = 0;
    //ID0 is PA8 -->  Switch 4
    //ID1 is PA9 -->  Switch 3
    //ID2 is PA10 --> Switch 2
    uint16_t nodeID = !HAL_GPIO_ReadPin(GPIOA, ID0_Pin);
    nodeID |= !HAL_GPIO_ReadPin(GPIOA, ID1_Pin) << 1;
    nodeID |= !HAL_GPIO_ReadPin(GPIOA, ID2_Pin) << 2;
    defaultNodeID = nodeID;

    /*---------- Apply EEPROM Settings ----------*/
    // Setting priority is EEPROM > Motor.h
    EEPROM eeprom;
    eeprom.get(0, boardConfig);
    if (boardConfig.configStatus != CONFIG_OK) // use default settings
    {
        boardConfig = BoardConfig_t{
            .configStatus = CONFIG_OK,
//            .canNodeId = defaultNodeID,
            .encoderHomeOffset = 0,
            .defaultMode = Motor::MODE_COMMAND_POSITION,
            .currentLimit = 2 * 1000,    // A
            .velocityLimit = 30 * motor.MOTOR_ONE_CIRCLE_SUBDIVIDE_STEPS, // r/s
            .velocityAcc = 100 * motor.MOTOR_ONE_CIRCLE_SUBDIVIDE_STEPS,   // r/s^2
            .calibrationCurrent=2000,
            .dce_kp = 200,
            .dce_kv = 80,
            .dce_ki = 300,
            .dce_kd = 300,
            .motor_temperature = 0.0,
            .enableMotorOnBoot=false,
            .enableStallProtect=false,
            .enableTempWatch=false,
        };
        eeprom.put(0, boardConfig);
    }
    boardConfig.enableTempWatch=false;
    //depends on 3 bits switch now
    boardConfig.canNodeId = defaultNodeID;
    motor.config.motionParams.encoderHomeOffset = boardConfig.encoderHomeOffset;
    motor.config.motionParams.ratedCurrent = boardConfig.currentLimit;
    motor.config.motionParams.ratedVelocity = boardConfig.velocityLimit;
    motor.config.motionParams.ratedVelocityAcc = boardConfig.velocityAcc;
    motor.motionPlanner.velocityTracker.SetVelocityAcc(boardConfig.velocityAcc);
    motor.motionPlanner.positionTracker.SetVelocityAcc(boardConfig.velocityAcc);
    motor.config.motionParams.caliCurrent = boardConfig.calibrationCurrent;
    motor.config.ctrlParams.dce.kp = boardConfig.dce_kp;
    motor.config.ctrlParams.dce.kv = boardConfig.dce_kv;
    motor.config.ctrlParams.dce.ki = boardConfig.dce_ki;
    motor.config.ctrlParams.dce.kd = boardConfig.dce_kd;
    motor.config.ctrlParams.stallProtectSwitch = boardConfig.enableStallProtect;

    //SendOne();
    //printf("encoderHomeOffset[%d] ratedCurrent[%d] ratedVelocity[%d] ratedVelocityAcc[%d]\r\n" , boardConfig.encoderHomeOffset, boardConfig.currentLimit, boardConfig.velocityLimit, boardConfig.velocityAcc);
    //printf("velocityTracker[%d] positionTracker[%d] caliCurrent[%d] \r\n" , boardConfig.velocityAcc, boardConfig.velocityAcc);
    //printf("kp[%d] kv[%d] ki[%d] kd[%d]\r\n" , boardConfig.dce_kp, boardConfig.dce_kv, boardConfig.dce_ki, boardConfig.dce_kd);
    //uint32_t apb2Freq = HAL_RCC_GetPCLK2Freq();
    //printf("APB2 Frequency: %lu Hz\r\n", apb2Freq);
    //printf("defaultNodeID: %d",defaultNodeID);
    /*---------------- Init Motor ----------------*/
    motor.AttachDriver(&tb67H450);
    motor.AttachEncoder(&mt6816);
    motor.controller->Init();
    motor.driver->Init();
    motor.encoder->Init();


    /*------------- Init peripherals -------------*/
    button1.SetOnEventListener(OnButton1Event);
    button2.SetOnEventListener(OnButton2Event);


    /*------- Start Close-Loop Control Tick ------*/
    HAL_Delay(100);
    HAL_TIM_Base_Start_IT(&htim1);  // 100Hz
    HAL_TIM_Base_Start_IT(&htim4);  // 20kHz

    if (button1.IsPressed() && button2.IsPressed())
        encoderCalibrator.isTriggered = true;
//    printf("start motor %d\r\n", defaultNodeID);
    //SendOne();

    for (;;)
    {
//        if ( encoderCalibrator.FlashRun() == 0)
            encoderCalibrator.TickMainLoop();

        if (boardConfig.configStatus == CONFIG_COMMIT)
        {
            boardConfig.configStatus = CONFIG_OK;
            eeprom.put(0, boardConfig);
        } else if (boardConfig.configStatus == CONFIG_RESTORE)
        {
            eeprom.put(0, boardConfig);
            HAL_NVIC_SystemReset();
        }
    }
}

/* Event Callbacks -----------------------------------------------------------*/
//let's add a global count in here for quick test
uint32_t count;
extern "C" void Tim1Callback100Hz()
{
    __HAL_TIM_CLEAR_IT(&htim1, TIM_IT_UPDATE);

    button1.Tick(10);
    button2.Tick(10);
    statusLed.Tick(10, motor.controller->state);
    //1s period to collect a temperature data
    if (boardConfig.enableTempWatch)
    {
        count ++;
        if ( count >= 100)
        {
            boardConfig.motor_temperature = AdcGetChipTemperature();
            count = 0;
        }
        if (count > 50)
        {
            statusLed.Status(1, true);
        }
        else
        {
            statusLed.Status(1, false);
        }
    }
}


extern "C" void Tim4Callback20kHz()
{
    __HAL_TIM_CLEAR_IT(&htim4, TIM_IT_UPDATE);

    if (encoderCalibrator.isTriggered)
        encoderCalibrator.Tick20kHz();
    else
        motor.Tick20kHz();
}


void OnButton1Event(Button::Event _event)
{
    switch (_event)
    {
        case ButtonBase::UP:
            break;
        case ButtonBase::DOWN:

            break;
        case ButtonBase::LONG_PRESS:
            encoderCalibrator.isTriggered = true;
            encoderCalibrator.Tick20kHz();
            encoderCalibrator.TickMainLoop();
//            HAL_NVIC_SystemReset();
//            encoderCalibrator.TestFlash();
            break;
        case ButtonBase::CLICK:
            //printf("angle: %d\n",mt6816.UpdateAngle());
            printf("KEY1\r\n");
            if (motor.controller->modeRunning != Motor::MODE_STOP)
            {
                boardConfig.defaultMode = motor.controller->modeRunning;
                motor.controller->requestMode = Motor::MODE_STOP;
            } else
            {
                motor.controller->requestMode = static_cast<Motor::Mode_t>(boardConfig.defaultMode);
            }
            break;
    }
}


void OnButton2Event(Button::Event _event)
{
    switch (_event)
    {
        case ButtonBase::UP:
            break;
        case ButtonBase::DOWN:
            break;
        case ButtonBase::LONG_PRESS:
            switch (motor.controller->modeRunning)
            {
                case Motor::MODE_COMMAND_CURRENT:
                case Motor::MODE_PWM_CURRENT:
                    motor.controller->SetCurrentSetPoint(0);
                    break;
                case Motor::MODE_COMMAND_VELOCITY:
                case Motor::MODE_PWM_VELOCITY:
                    motor.controller->SetVelocitySetPoint(0);
                    break;
                case Motor::MODE_COMMAND_POSITION:
                case Motor::MODE_PWM_POSITION:
                    motor.controller->SetPositionSetPoint(0);
                    break;
                case Motor::MODE_COMMAND_Trajectory:
                case Motor::MODE_STEP_DIR:
                case Motor::MODE_STOP:
                    break;
            }
            break;
        case ButtonBase::CLICK:
            printf("KEY2\r\n");
            motor.controller->ClearStallFlag();
            break;
    }
}

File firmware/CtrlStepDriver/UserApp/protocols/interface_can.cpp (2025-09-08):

#include "common_inc.h"
#include "configurations.h"
#include <can.h>


extern Motor motor;
extern EncoderCalibrator encoderCalibrator;

CAN_TxHeaderTypeDef txHeader =
    {
        .StdId = 0x00,
        .ExtId = 0x00,
        .IDE = CAN_ID_STD,
        .RTR = CAN_RTR_DATA,
        .DLC = 8,
        .TransmitGlobalTime = DISABLE
    };

void SendOne() {
    printf("send one begin\r\n");
    uint8_t TxData[8] = {0x01, 0x02, 0x03, 0x04, 0x05, 0x06, 0x07, 0x08};
    CAN_TxHeaderTypeDef TxHeader;

    TxHeader.StdId = 0x123;
    TxHeader.ExtId = 0x00;
    TxHeader.RTR = CAN_RTR_DATA;
    TxHeader.IDE = CAN_ID_STD;
    TxHeader.DLC = 8;
    TxHeader.TransmitGlobalTime = DISABLE;

    if (HAL_CAN_AddTxMessage(&hcan, &TxHeader, TxData, &TxMailbox) != HAL_OK)
    {
        Error_Handler();
    }
    printf("send one \r\n");
}

void OnCanCmd(uint8_t _cmd, uint8_t* _data, uint32_t _len)
{
    float tmpF;
    int32_t tmpI;

    switch (_cmd)
    {
        // 0x00~0x0F No Memory CMDs
        case 0x01:  // Enable Motor
            motor.controller->requestMode = (*(uint32_t*) (RxData) == 1) ?
                                            Motor::MODE_COMMAND_VELOCITY : Motor::MODE_STOP;
            break;
        case 0x02:  // Do Calibration
            encoderCalibrator.isTriggered = true;
            break;
        case 0x03:  // Set Current SetPoint
            if (motor.controller->modeRunning != Motor::MODE_COMMAND_CURRENT)
                motor.controller->SetCtrlMode(Motor::MODE_COMMAND_CURRENT);
            motor.controller->SetCurrentSetPoint((int32_t) (*(float*) RxData * 1000));
            break;
        case 0x04:  // Set Velocity SetPoint
            if (motor.controller->modeRunning != Motor::MODE_COMMAND_VELOCITY)
            {
                motor.config.motionParams.ratedVelocity = boardConfig.velocityLimit;
                motor.controller->SetCtrlMode(Motor::MODE_COMMAND_VELOCITY);
            }
            motor.controller->SetVelocitySetPoint(
                (int32_t) (*(float*) RxData *
                           (float) motor.MOTOR_ONE_CIRCLE_SUBDIVIDE_STEPS));
            //printf("vel: %d\n", (int32_t) (*(float*) RxData));
            break;
        case 0x05:  // Set Position SetPoint
            if (motor.controller->modeRunning != Motor::MODE_COMMAND_POSITION)
            {
                motor.config.motionParams.ratedVelocity = boardConfig.velocityLimit;
                motor.controller->SetCtrlMode(Motor::MODE_COMMAND_POSITION);
            }
            motor.controller->SetPositionSetPoint(
                (int32_t) (*(float*) RxData * (float) motor.MOTOR_ONE_CIRCLE_SUBDIVIDE_STEPS));
            //printf("SET MOTOR[0x05] POSITION[]\r\n");
            if (_data[4]) // Need Position & Finished ACK
            {
                tmpF = motor.controller->GetPosition();
                auto* b = (unsigned char*) &tmpF;
                for (int i = 0; i < 4; i++)
                    _data[i] = *(b + i);
                _data[4] = motor.controller->state == Motor::STATE_FINISH ? 1 : 0;
                txHeader.StdId = (boardConfig.canNodeId << 7) | 0x23;
                CAN_Send(&txHeader, _data);
            }
            break;
        case 0x06:  // Set Position with Time
            if (motor.controller->modeRunning != Motor::MODE_COMMAND_POSITION)
                motor.controller->SetCtrlMode(Motor::MODE_COMMAND_POSITION);
            motor.controller->SetPositionSetPointWithTime(
                (int32_t) (*(float*) RxData * (float) motor.MOTOR_ONE_CIRCLE_SUBDIVIDE_STEPS),
                *(float*) (RxData + 4));
            if (_data[4]) // Need Position & Finished ACK
            {
                tmpF = motor.controller->GetPosition();
                auto* b = (unsigned char*) &tmpF;
                for (int i = 0; i < 4; i++)
                    _data[i] = *(b + i);
                _data[4] = motor.controller->state == Motor::STATE_FINISH ? 1 : 0;
                txHeader.StdId = (boardConfig.canNodeId << 7) | 0x23;
                CAN_Send(&txHeader, _data);
            }
            break;
        case 0x07:  // Set Position with Velocity-Limit
        {
            if (motor.controller->modeRunning != Motor::MODE_COMMAND_POSITION)
            {
                motor.config.motionParams.ratedVelocity = boardConfig.velocityLimit;
                motor.controller->SetCtrlMode(Motor::MODE_COMMAND_POSITION);
            }
            motor.config.motionParams.ratedVelocity =
                (int32_t) (*(float*) (RxData + 4) * (float) motor.MOTOR_ONE_CIRCLE_SUBDIVIDE_STEPS);
            motor.controller->SetPositionSetPoint(
                (int32_t) (*(float*) RxData * (float) motor.MOTOR_ONE_CIRCLE_SUBDIVIDE_STEPS));
            // Always Need Position & Finished ACK
            tmpF = motor.controller->GetPosition();
            auto* b = (unsigned char*) &tmpF;
            for (int i = 0; i < 4; i++)
                _data[i] = *(b + i);
            _data[4] = motor.controller->state == Motor::STATE_FINISH ? 1 : 0;
            txHeader.StdId = (boardConfig.canNodeId << 7) | 0x23;
            CAN_Send(&txHeader, _data);
        }
            break;

            // 0x10~0x1F CMDs with Memory
        case 0x11:  // Set Node-ID and Store to EEPROM
            boardConfig.canNodeId = *(uint32_t*) (RxData);
            if (_data[4])
                boardConfig.configStatus = CONFIG_COMMIT;
            break;
        case 0x12:  // Set Current-Limit and Store to EEPROM
            motor.config.motionParams.ratedCurrent = (int32_t) (*(float*) RxData * 1000);
            boardConfig.currentLimit = motor.config.motionParams.ratedCurrent;
            if (_data[4])
                boardConfig.configStatus = CONFIG_COMMIT;
            break;
        case 0x13:  // Set Velocity-Limit and Store to EEPROM
            motor.config.motionParams.ratedVelocity =
                (int32_t) (*(float*) RxData *
                           (float) motor.MOTOR_ONE_CIRCLE_SUBDIVIDE_STEPS);
            boardConfig.velocityLimit = motor.config.motionParams.ratedVelocity;
            if (_data[4])
                boardConfig.configStatus = CONFIG_COMMIT;
            break;
        case 0x14:  // Set Acceleration （and Store to EEPROM）
            tmpF = *(float*) RxData * (float) motor.MOTOR_ONE_CIRCLE_SUBDIVIDE_STEPS;
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

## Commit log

2024-10-28 添加机械臂代码和模型
    [机械臂配料表（不包含相机和夹爪）.xls]
2024-10-29 更新配料表的价格
    [机械臂配料表（不包含相机和夹爪）.xls]
2024-11-16 修改逆解计算的一些bug
2024-11-16 配料表添加淘宝链接
    [机械臂配料表（不包含相机和夹爪）.xls]
2025-02-20 新建 Images
2025-02-25 新版jyker
    [42底盖第四版.STL, 42柔轮内第四版.STL, 42柔轮第四版.STL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]
2025-02-25 更新配料表
    [机械臂配料表（不包含相机和夹爪）.xls]
2025-02-28 更改电路板链接
2025-02-28 不要控制板了
2025-03-04 配料表少了个定位销
    [机械臂配料表（不包含相机和夹爪）.xls]
2025-03-06 更新夹爪
    [01齿轮电机端.STL, 02双层齿轮.STL, 07夹爪右.STL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]
2025-03-11 更新电机高度
    [机械臂配料表（不包含相机和夹爪）.xls]
2025-03-11 修改底座螺钉
2025-03-12 修改夹爪代码
2025-03-13 配件同步轮数量修改
    [机械臂配料表（不包含相机和夹爪）.xls]
2025-03-23 修改电路板连接
    [机械臂配料表（不包含相机和夹爪）.xls]
2025-04-07 增加摆线减速器以及软件设置
    [42底盖第四版.STL, 42柔轮内第四版.STL, 42柔轮第四版.STL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]
2025-04-09 更改SerialPortStream 串口工具
2025-05-15 添加谐波和摆线的配料表
2025-05-15 添加摆线和谐波的配料表
    [配料表.xls]
2025-05-16 修改摆线配料表
    [配料表.xls]
2025-05-30 上传操作说明
2025-06-12 开源摆线减速器的SW 文件
    [10_15_4.SLDPRT, 12_18_4.SLDPRT, 15_21_4.SLDPRT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]
2025-07-03 提交闭环电机电路板代码
    [configurations.h, stlink.cfg]
2025-07-04 提交金属减速器版本
    [01齿轮电机端.SLDPRT, 02双层齿轮.SLDPRT, 03夹爪左.SLDPRT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]
2025-07-04 提交金属版本STL
    [42减速器盖子.STL, Jyker机械臂（金属减速器版本）.3mf, joint1.STL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]
2025-07-16 更新机械臂初始化值
2025-08-21 自制FOC 版本
2025-09-08 做个电机的上位机以及电机的说明文档
    [stlink.cfg]
2025-09-08 更新文档说明
